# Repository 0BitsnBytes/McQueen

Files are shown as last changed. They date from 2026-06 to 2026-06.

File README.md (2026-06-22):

<h1 align="center">
  <br>
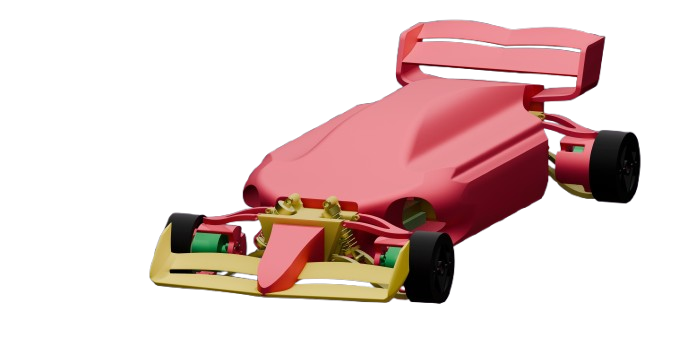
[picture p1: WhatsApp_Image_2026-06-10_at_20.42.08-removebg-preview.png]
McQueen
  
  <br>
  McQueen
  <br>
</h1>

<h4 align="center">
AWD RC Car • Custom ESC
</h4>

<p align="center">
  <a href="#specifications">Specifications</a> •
  <a href="#links">Links</a> •
  <a href="#custom-esc">Custom ESC</a> •
  <a href="#chassis">Chassis</a> •
  <a href="#build-guide">Build Guide</a> •
  <a href="#zine">Zine</a> •
  <a href="#credits">Credits</a>
</p>

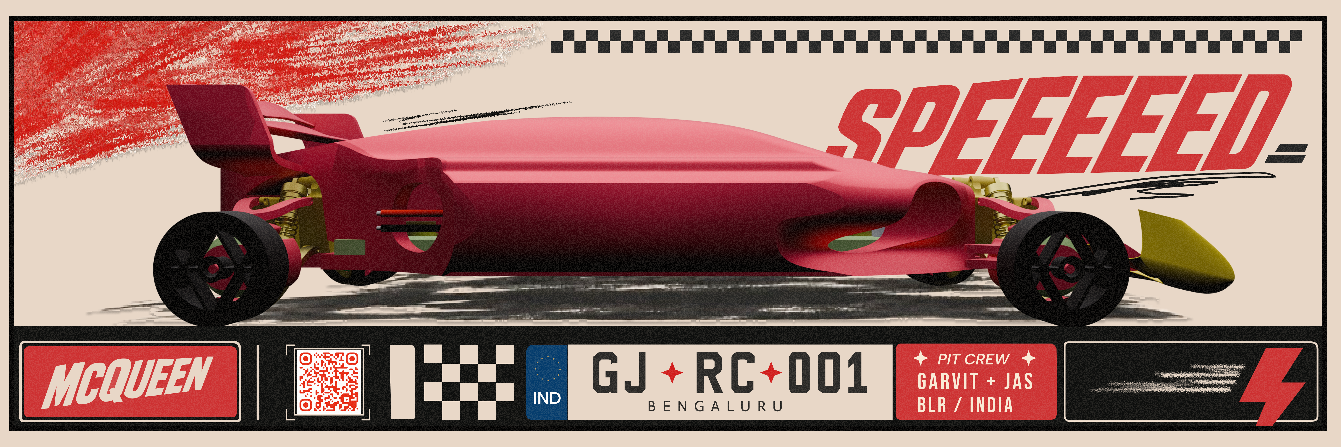
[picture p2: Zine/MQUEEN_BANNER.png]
McQueen Banner


<p>&nbsp;</p>

McQueen is an AWD RC car with 4 drone-hub-motors. Featuring a DIY 80A ESC with current sense and braking. A fully custom double wishbone suspension with an aerodynamic chassis all powered by 2 6S Lipo batteries. 

Most RC cars are seen as toys, McQueen is definitely not one of those. It is an attempt to combine high current electronics, aerodynamic bodies, and complex suspension geometries into a small RC Car. 

---

<h2 id="specifications">Specifications</h2>

<table>
<tr>
<td><b>Drive System</b></td>
<td>All Wheel Drive (AWD)</td>
</tr>

<tr>
<td><b>Motors</b></td>
<td>4× Drone Hub Motors</td>
</tr>

<tr>
<td><b>Battery</b></td>
<td>2× 6S LiPo Batteries</td>
</tr>

<tr>
<td><b>Motor Controller</b></td>
<td>Custom STM32 ESC</td>
</tr>

<tr>
<td><b>Suspension</b></td>
<td>Double Wishbone</td>
</tr>

<tr>
<td><b>Steering</b></td>
<td>Ackermann Geometry</td>
</tr>

<tr>
<td><b>Braking</b></td>
<td>Electronic Dynamic Braking</td>
</tr>

<tr>
<td><b>Chassis</b></td>
<td>Fully Custom 3D Printed Design</td>
</tr>
</table>

---

<h2 id="links">Links</h2>

If clicking the link gives 403 Forbidden, copy paste the link into your browser directly

| Resource | Link |
|---|---|
| CAD Assembly | [Onshape document](https://cad.onshape.com/documents/fc565ca3851146bee43ab660/w/08fa01b8b529e8822f765509/e/27cf93230e8926e0ab4158b0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)|
| PCB Files | [Kicanvas Viewer](https://kicanvas.org/?repo=https%3A%2F%2Fgithub.com%2F0BitsnBytes%2Fmcqueen-pcb-file-for-kicanvas) |
| Bill of Materials for ESC| [BOM for ESC](https://github.com/0BitsnBytes/McQueen/blob/main/BOM/MCQUEEEN%20-%20ESC%20BOM.csv) |
| Bill of Materials | [BOM for Car](https://github.com/0BitsnBytes/McQueen/blob/main/BOM/MCQUEEEN%20-%20ALL%20compnents.csv) |

---

<h2 id="custom-esc">Custom ESC</h2>

The ESC combines current sensing, protection circuitry, braking, and motor feedback into a compact high-current first PCB :).

<h3>Features</h3>

<ul>
<li>STM32F411CEU6 Microcontroller</li>
<li>IR21084 MOSFET Driver</li>
<li>AS5600 Position Sensor Interface</li>
<li>INA180 Current Sense Amplifier</li>
<li>MOSFET Temperature Monitoring</li>
<li>SMCJ54CA TVS Protection</li>
<li>RGB Status LED</li>
<li>Electronic Braking</li>
</ul>

<h3>Schematic</h3>

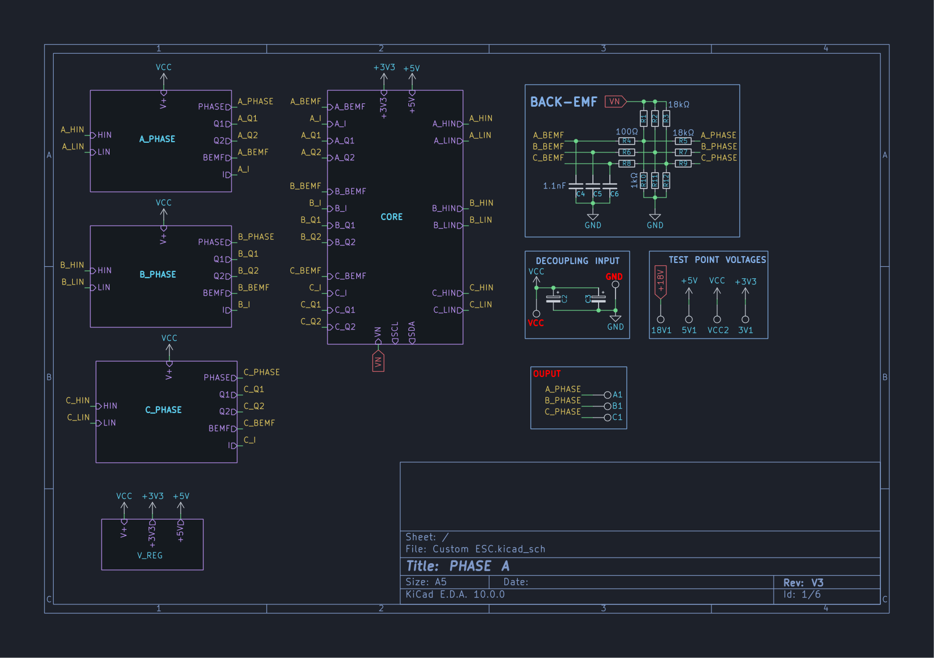
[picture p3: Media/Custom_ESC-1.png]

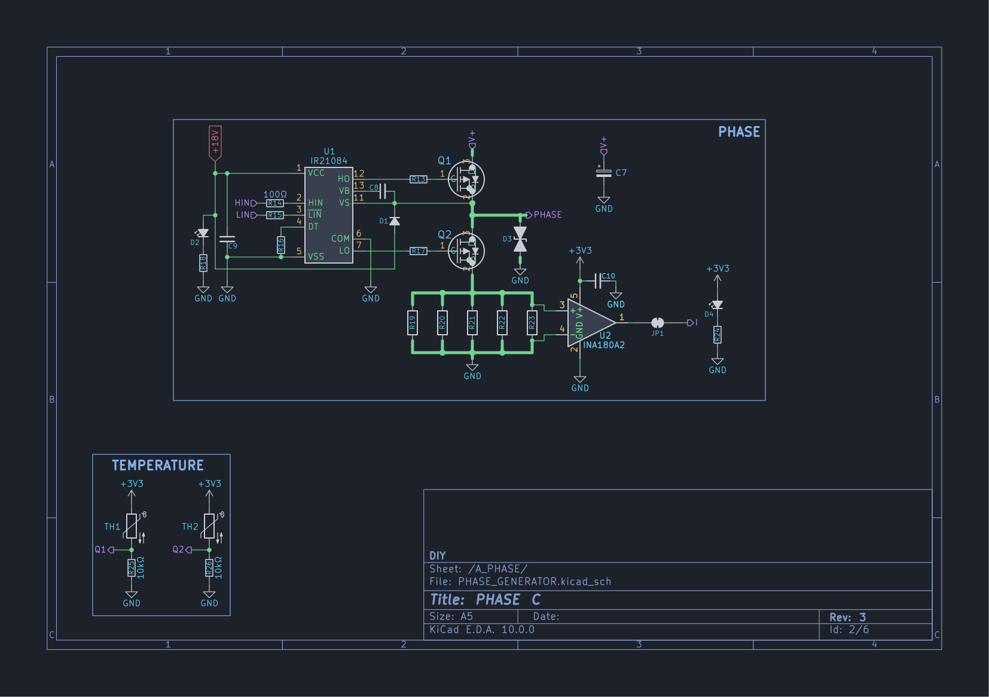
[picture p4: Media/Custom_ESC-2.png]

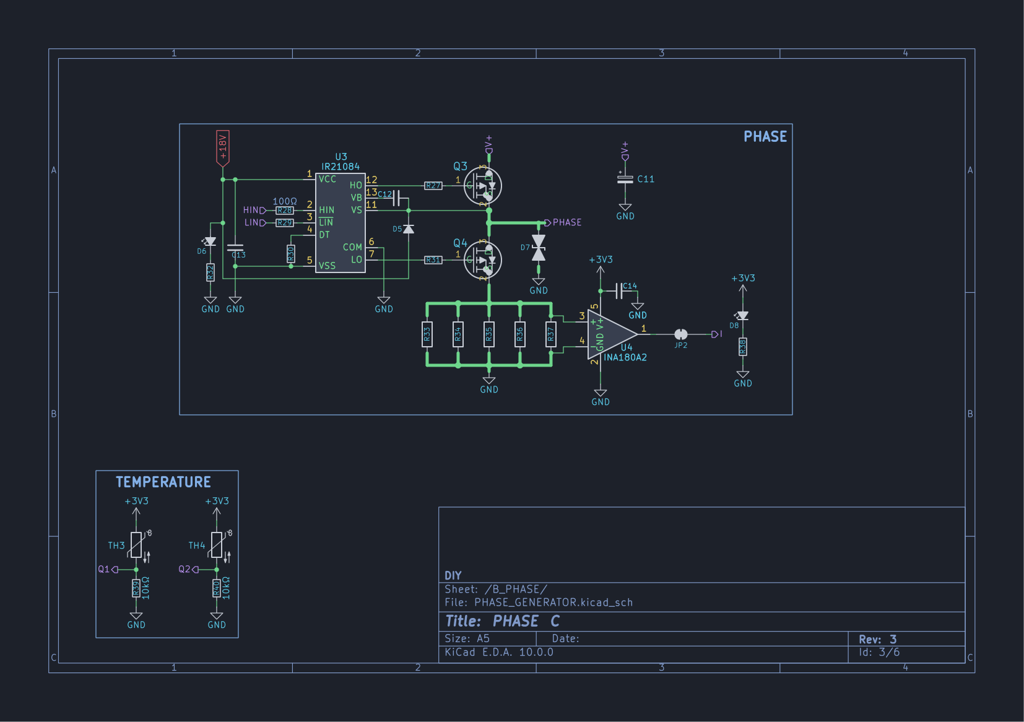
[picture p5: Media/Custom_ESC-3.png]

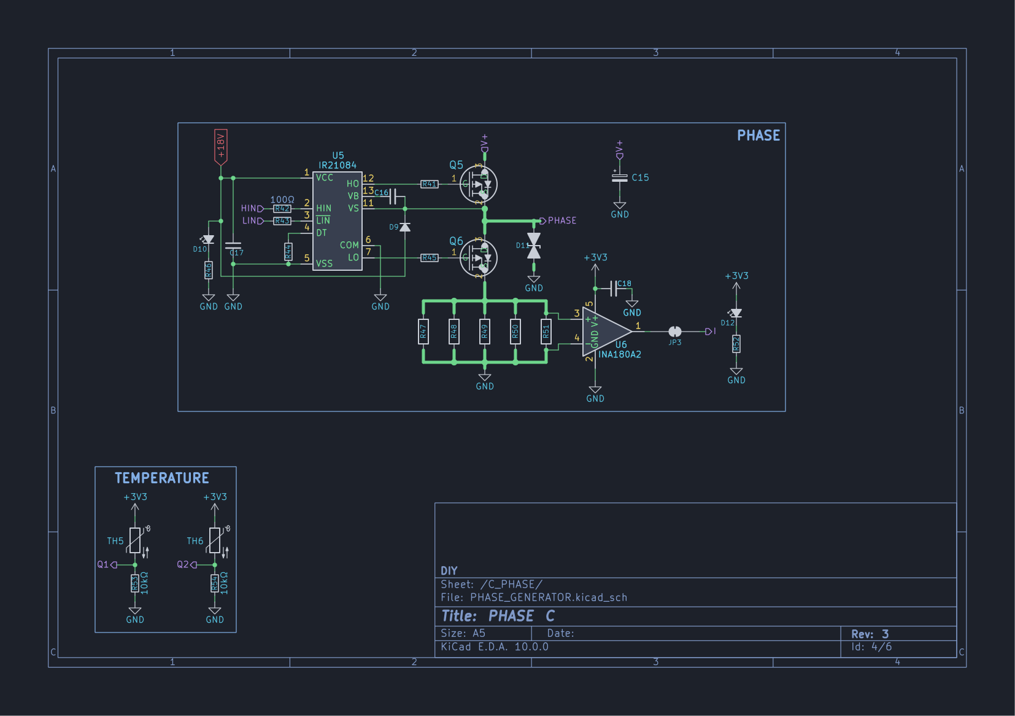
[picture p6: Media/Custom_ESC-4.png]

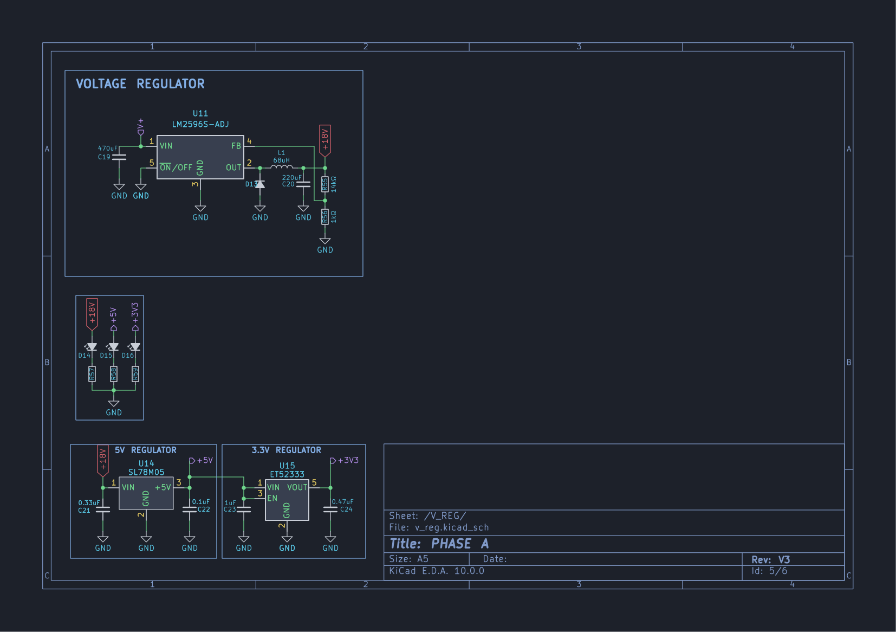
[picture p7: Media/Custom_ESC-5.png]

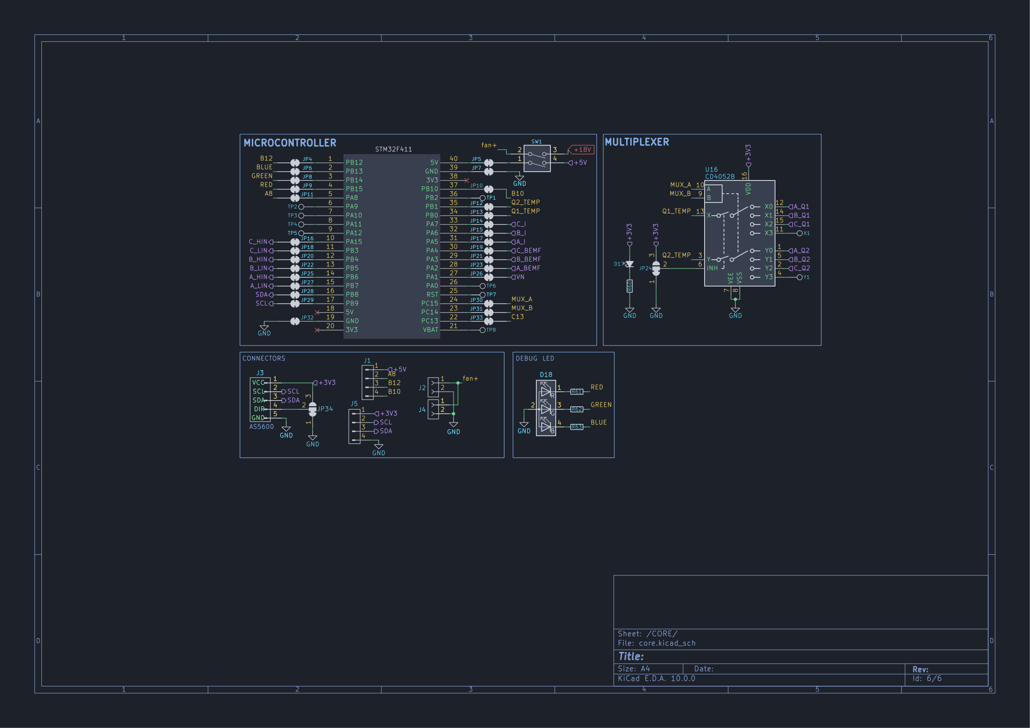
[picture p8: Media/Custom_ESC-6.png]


<h3>PCB Layers</h3>

<h4>Layer 1</h4>

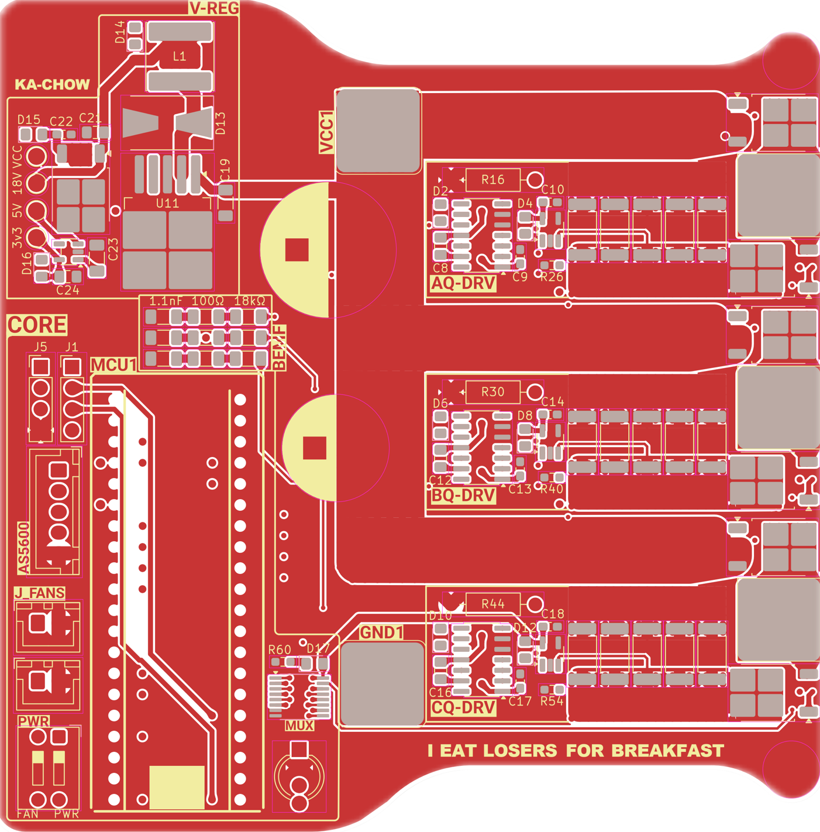
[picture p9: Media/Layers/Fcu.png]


<h4>Layer 2</h4>

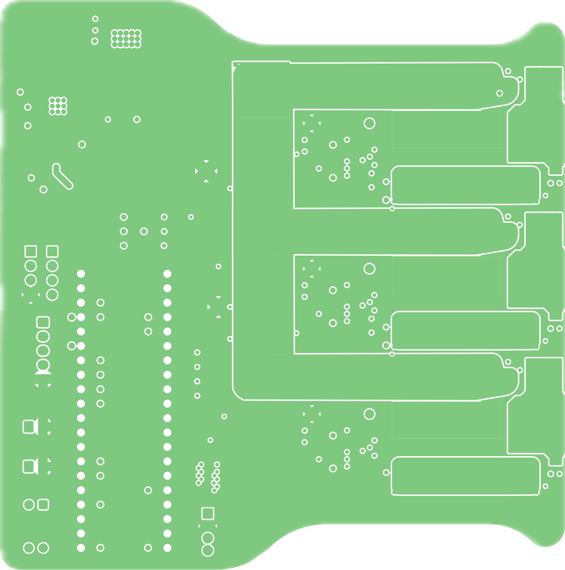
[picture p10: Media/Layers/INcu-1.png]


<h4>Layer 3</h4>

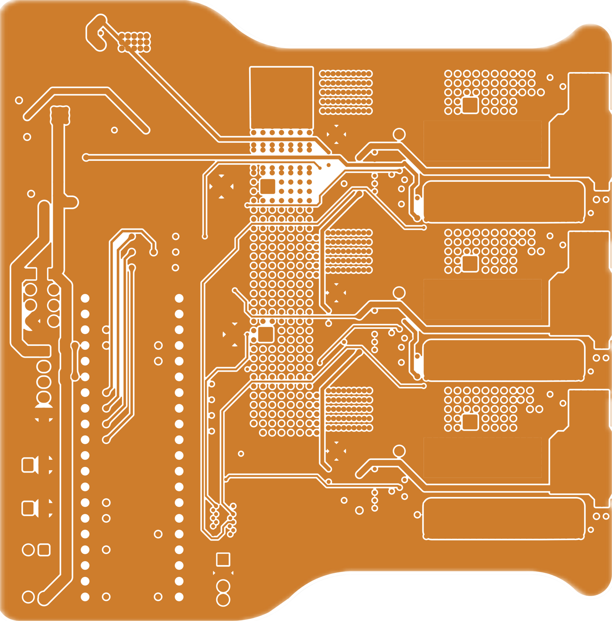
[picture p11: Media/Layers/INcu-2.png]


<h4>Layer 4</h4>

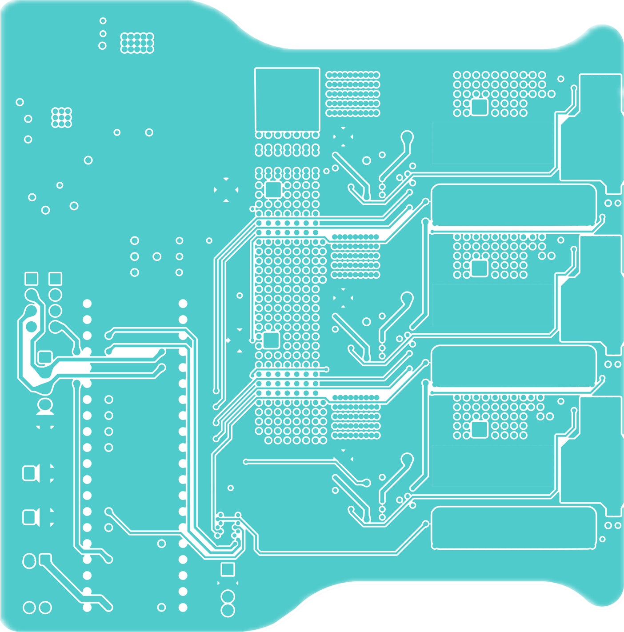
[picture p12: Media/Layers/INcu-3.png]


<h4>Layer 5</h4>

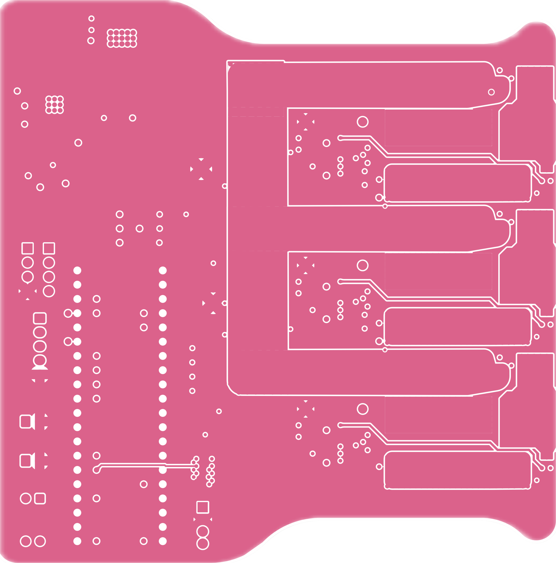
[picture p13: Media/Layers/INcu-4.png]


<h4>Layer 6</h4>

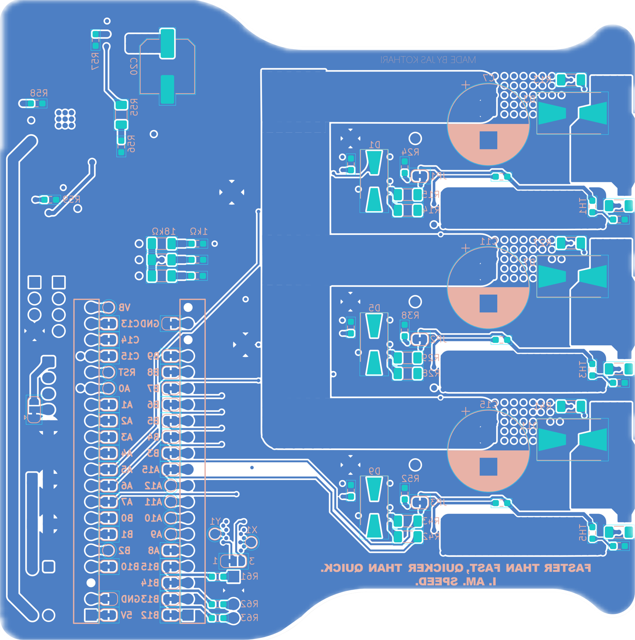
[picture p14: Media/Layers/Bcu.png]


---

<h3>Board Views</h3>

<h4>Front</h4>

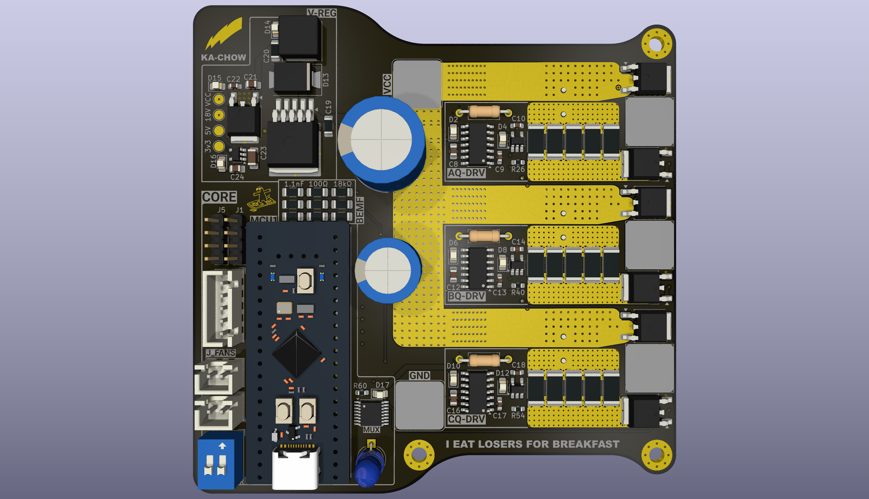
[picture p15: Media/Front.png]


<h4>Back</h4>

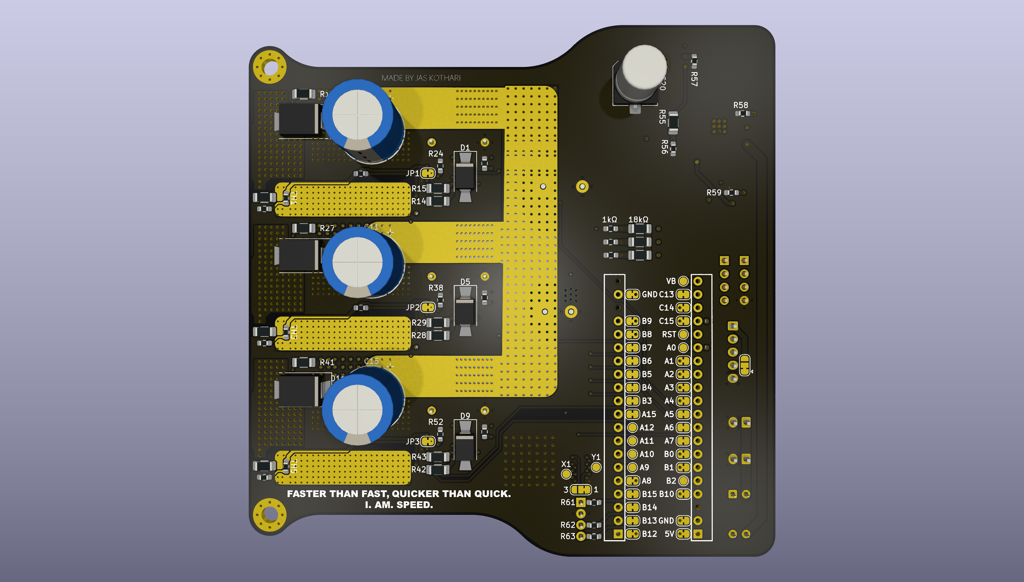
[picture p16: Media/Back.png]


---

<h2 id="chassis">Chassis</h2>

The Chassis features a fully custom double wishbone suspension system, Ackermann steering, aerodynamic chassis, and front and rear wings.

<h3>Suspension</h3>

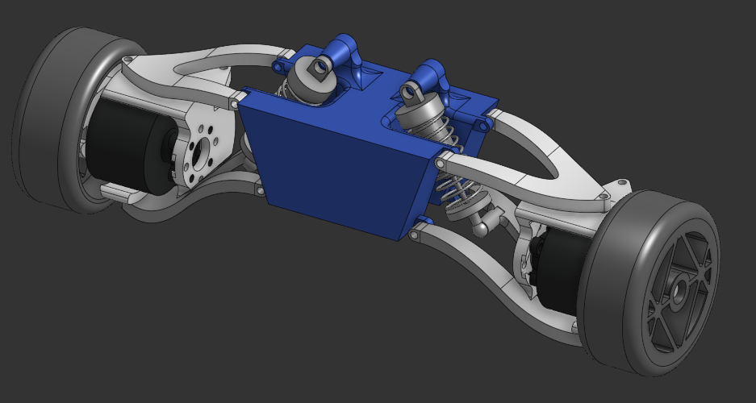
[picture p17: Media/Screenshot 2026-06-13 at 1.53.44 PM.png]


<h3>Aerodynamics</h3>


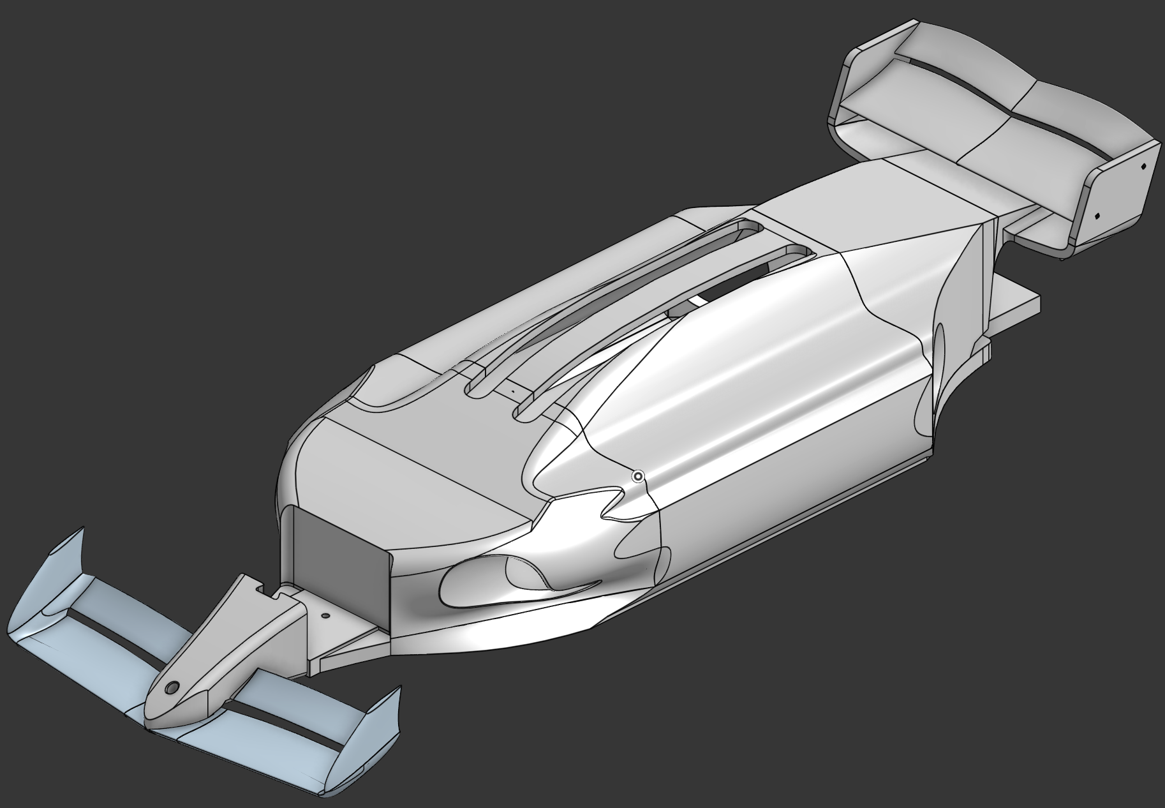
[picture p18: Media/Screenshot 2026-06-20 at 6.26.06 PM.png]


---

<h2 id="build-guide">Build Guide</h2>

McQueen consists of two major assemblies:

1. Custom ESC
2. 3D Printed Chassis

<h3>ESC</h3>

<ol>
<li>Upload the Gerber files to your preferred PCB manufacturer.</li>
<li>Select 2oz copper during fabrication.</li>
<li>Order the PCB.</li>
<li>Populate using the ESC BOM.</li>
</ol>

<h3>Chassis</h3>

<ol>
<li>Download the STL files.</li>
<li>Print all components in PETG or equivalent material.</li>
<li>Purchase hardware from the chassis BOM.</li>
<li>Follow the Onshape assembly.</li>
<li>Insert Carbon fibre square tubes in wings</li>
<li>Insert peices of filament throughout the chassis to secure it</li>
<li>Install electronics and drivetrain.</li>
<li>Secure components using M3 hardware.</li>
<li>Use cyanoacrylate adhesive where necessary.</li>
<li>Put in the magnets into the slots provided in the main chassis to make it easier to open and close the chassis.</li>
</ol>

---

<h2 id="zine">Zine</h2>

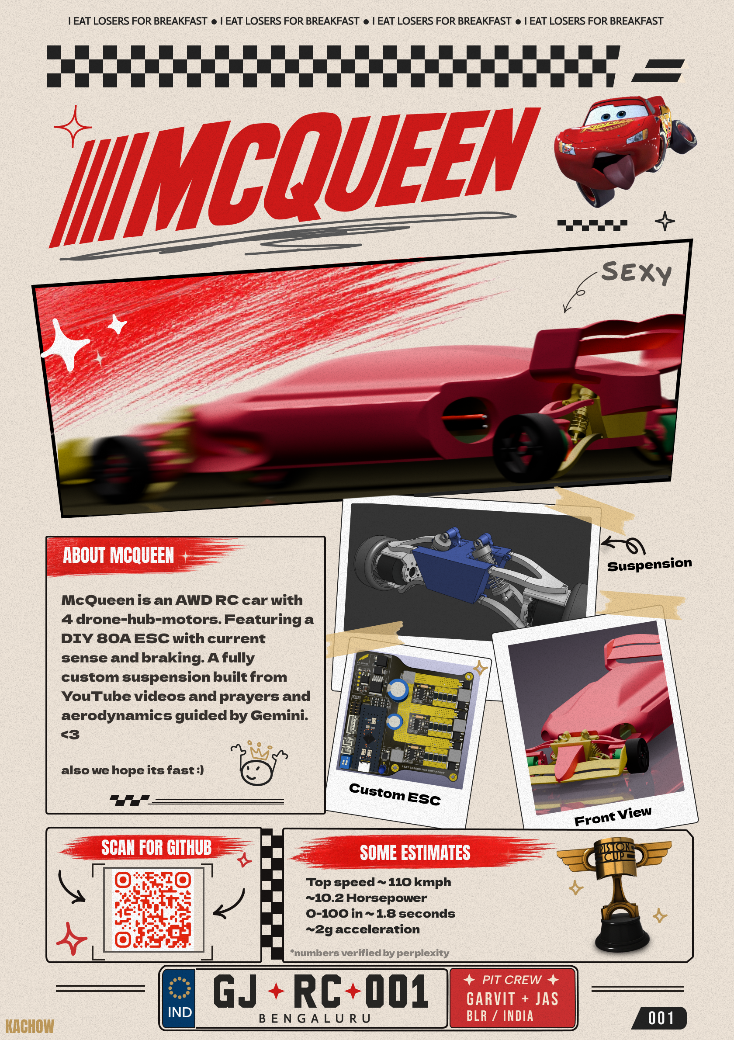
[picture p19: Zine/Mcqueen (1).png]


---

<h2 id="credits">Credits</h2>

This project uses:

<ul>
<li>KiCad for PCB Design</li>
<li>Onshape for CAD</li>
<li>Blender for Rendering</li>
<li>Figma for Documentation & Zine Design</li>
</ul>

---

<h2>License</h2>

GPL-3.0


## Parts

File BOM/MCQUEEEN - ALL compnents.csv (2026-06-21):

Component name | Quantity | Price | Total price | Link | Total Money required
FA3115 400KV BLDC | 4 | Rs2,899.00 | Rs11,596.00 | https://hitechxyz.in/products/flycci-fpv-brushless-motors-fa3115-400kv-1?_pos=1&_psq=fa3115&_ss=e&_v=1.0 | Rs64,076.08
4200mAh 6S 35C LiPo | 2 | Rs5,694.00 | Rs11,388.00 | https://robu.in/product/orange-4200mah-6s-40c80c-lithium-polymer-battery-pack-lipo?gad_source=1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 | $679.2724463624
FS-i6X RX TX | 1 | Rs6,599.00 | Rs6,599.00 | https://robu.in/product/flysky-fs-i6x-2-4ghz-10ch-afhds-2a-rc-transmitter-with-fs-ia10b-2-4ghz-10ch-receiver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 | 135.85448927248 hours
Teensy 4.1 | 1 | Rs3,399.00 | Rs3,399.00 | https://robu.in/product/teensy-4-1-development-board-with-headers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 | 679.2724463624 Koi
1/10 Scale RC wheels | 1 | Rs4,395.00 | Rs4,395.00 | https://www.amazon.in/801GTX-Brushless-Wheels-Racing-Serpent/dp/B09474HB4D
Shock Absorber | 2 | Rs532.00 | Rs1,064.00 | https://robu.in/product/wltoys-a959-aluminum-shock-absorber-1-pair
ESC PCB | 1 | Rs7,583.56 | Rs7,583.56 | https://jlcpcb.com/
ESC Components | 4 | Rs2,601.63 | Rs10,406.52 | --
Velcro Straps | 1 | Rs284.00 | Rs284.00 | https://www.amazon.in/Bonzella-Adjustable-Organizer-Multipurpose-Securing/dp/B0D41DKW5M
Servos for turning | 1 | Rs1,338.00 | Rs1,338.00 | https://robu.in/product/pro-range-ds3225-25kgcm-metal-gear-digital-servo-motor-180-degree/?gad_source=1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
Servo horn | 1 | Rs69.00 | Rs69.00 | https://robu.in/product/cnc-aluminum-steering-servo-horn-arm-futaba-standard-25t-aluminum/
Voltage checker | 1 | Rs95.00 | Rs95.00 | https://quartzcomponents.com/collections/all/products/lipo-battery-vltage-testerlow-voltage-buzzer-alarm
Ball joints | 1 | Rs1,924.00 | Rs1,924.00 | https://www.amazon.in/ShareGoo-Aluminum-Holder-TRAXXAS-Crawler/dp/B07TYXX4N3
Bearings | 1 | Rs65.00 | Rs65.00 | https://robu.in/product/radial-ball-bearing-625zz-for-3d-printer-robot-4pcs/
Solder Paste | 1 | Rs372.00 | Rs372.00 | https://www.amazon.in/MOBILE-WORLD-Solder-Paste-Rework/dp/B0DR2YWY73?mcid=31cbd004a3753bd189e576be226896a2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
Solder Flux | 1 | Rs37.00 | Rs37.00 | https://quartzcomponents.com/products/rma-223-solder-flux-paste?variant=39532236931256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
Carbon fibre | 2 | Rs54.00 | Rs108.00 | https://robu.in/product/pultruded-square-carbon-hollow-fiber-tube-22mmod-1mmid-400mml-2pcs/
3mm Rod | 1 | Rs293.00 | Rs293.00 | https://robu.in/product/pultruded-carbon-fiber-tube-hollow-3mmod-1-5mm-id-1000mm-pack-of-2/?gad_source=1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
Filament | 4 | Rs600.00 | Rs2,400.00 | https://india.numakers.com/products/petg-hs-filament?variant=43307604082857
5x3mm disc magnet | 16 | Rs10.00 | Rs160.00 | https://onlyscrews.in/products/5mm-diameter-neodymium-disc-magnets-n35?variant=51060958789945
Misc hardware (screws, nuts, etc.) | 1 | Rs500.00 | Rs500.00 | https://onlyscrews.in/

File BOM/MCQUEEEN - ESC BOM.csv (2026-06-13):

Value | Reference | Footprint | Datasheet | Qty | Link | Unit Price (₹) | Total Price (₹) | Comment
5mΩ | R19,R20,R21,R22,R23,R33,R34,R35,R36,R37,R47,R48,R49,R50,R51 | Resistor_SMD:R_2512_6332Metric_Pad1.40x3.35mm_HandSolder |  | 15 | https://robu.in/product/1-month-warranty-305/#tab-questions | 5.00 | 75
330Ω | R18,R24,R32,R38,R46,R52,R57,R58,R59,R60,R61 | Resistor_SMD:R_0603_1608Metric_Pad0.98x0.95mm_HandSolder | https://robu.in/wp-content/uploads/2024/06/C67088.pdf | 11 | https://quartzcomponents.com/collections/all/products/rc0603jr07330rl-yageo-330-ohm-0603-package-1-10w-smd-resistor-5-tolerance-pack-of-20-pieces | 5.00 | 5 | Pack has only 20 peices
LED_Small_Filled | D2,D4,D6,D8,D10,D12,D14,D15,D16,D17 | LED_SMD:LED_0805_2012Metric_Pad1.15x1.40mm_HandSolder |  | 5 | https://quartzcomponents.com/collections/all/products/red-led-smd-0805-package-pack-of-50 | 25.00 | 25 | Pack has only 50 peices
LED_SMall_Filled | D2,D4,D6,D8,D10,D12,D14,D15,D16,D18 | LED_SMD:LED_0805_2012Metric_Pad1.15x1.40mm_HandSolder |  | 5 | https://quartzcomponents.com/collections/all/products/green-led-smd-0805-package-pack-of-50 | 24.00 | 24 | Pack has only 50 peices
100Ω | R4,R6,R8,R14,R15,R28,R29,R42,R43 | Resistor_SMD:R_1206_3216Metric_Pad1.30x1.75mm_HandSolder | https://robu.in/wp-content/uploads/2024/06/C67088.pdf | 9 | https://robu.in/product/1206w4f1000t5e-uniohm-royal-ohm-250mw-thick-film-resistors-200v-%c2%b11-100%cf%89-1206-chip-resistor-surface-mount-rohs/ | 0.38 | 3.42
0.1uF | C9,C10,C13,C14,C17,C18,C22 | Capacitor_SMD:C_0603_1608Metric_Pad1.08x0.95mm_HandSolder |  | 7 | https://robu.in/product/ac0603jrx7r9bb104-yageo-cap-ceramic-0-1uf-50v-x7r-5-pad-smd-0603-125c-automotive-aec-q200-t-r/ | 1.69 | 11.83
NCU18XH103F6SRB | TH1,TH2,TH3,TH4,TH5,TH6 | Resistor_SMD:R_0603_1608Metric_Pad0.98x0.95mm_HandSolder | https://robu.in/wp-content/uploads/2025/08/C162670.pdf | 6 | https://www.digikey.in/en/products/detail/murata-electronics/NCU18XH103F60RB/7363023 | 11.76 | 70.56
10kΩ | R25,R26,R39,R40,R53,R54 | Resistor_SMD:R_0603_1608Metric_Pad0.98x0.95mm_HandSolder |  | 6 | https://robu.in/product/rc0603jr-0710kl-yageo-res-10k-5-0-25w-0603-thick-film-pack-of-10/ | 0.36 | 2.16
10Ω | R13,R17,R27,R31,R41,R45 | Resistor_SMD:R_1206_3216Metric_Pad1.30x1.75mm_HandSolder | https://robu.in/wp-content/uploads/2024/12/royal-ohm-smd-res-datasheet.pdf | 6 | https://robu.in/product/mcwr12x10r0ftlmulticomp-prosmd-chip-resistor-10-ohm-%c2%b1-1-250-mw-1206-3216-metric-thick-film-general-purpose-pack-of-10/ | 0.32 | 1.92
18kΩ | R1,R2,R3,R5,R7,R9 | Resistor_SMD:R_1206_3216Metric_Pad1.30x1.75mm_HandSolder | https://robu.in/wp-content/uploads/2024/06/C17921.pdf | 6 | https://robu.in/product/1206w4f1802t5e-uniohm-royal-ohm-250mw-thick-film-resistors-200v-%c2%b1100ppm-%e2%84%83%c2%b11-18k%cf%89-1206-chip-resistor-surface-mou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 | 0.17 | 1.02
DMT10H009LK3-13 | Q1,Q2,Q3,Q4,Q5,Q6 | Package_TO_SOT_SMD:TO-252-2 | https://robu.in/wp-content/uploads/2025/08/C6540284.pdf | 6 | https://robu.in/product/dmt10h009lk3-13-diodes-incorporated-100v-90a-3w-9m%cf%8910v-2-5v-1-n-channel-to-252dpak-mosfets-rohs/ | 58.00 | 348
1kΩ | R10,R11,R12,R56 | Resistor_SMD:R_0603_1608Metric_Pad0.98x0.95mm_HandSolder | https://robu.in/wp-content/uploads/2024/07/C138242.pdf | 4 | https://robu.in/product/rc0603fr-071kl-yageo-smd-chip-resistor-1-kohm-%c2%b1-1-100-mw-0603-1608-metric-thick-film-general-purpose-pack-of-10/ | 0.18 | 0.72
0.47uF | C8,C12,C16,C24 | Capacitor_SMD:C_0805_2012Metric_Pad1.18x1.45mm_HandSolder | https://robu.in/wp-content/uploads/2024/09/C346225.pdf | 4 | https://robu.in/product/cl21b474kbfvpne-samsung-cap-ceramic-0-47uf-50v-x7r-10-pad-smd-0805-125c-t-r-automotive-aec-q200/ | 1.20 | 4.8
INA180A2 | U2,U4,U6 | Package_TO_SOT_SMD:SOT-23-5_HandSoldering | https://www.ti.com/lit/ds/symlink/ina180.pdf?HQS=dis-dk-null-digikeymode-dsf-pf-null-wwe&ts=1775967598102 | 3 | https://www.digikey.in/en/products/detail/texas-instruments/INA180A2IDBVR/8132987 | 31.76 | 95.28
IR21084 | U1,U3,U5 | Package_SO:SOIC-14_3.9x8.7mm_P1.27mm | https://www.infineon.com/dgdl/ir2108.pdf?fileId=5546d462533600a4015355c7dc321676 | 3 | https://robu.in/product/ir21084strpbf-infenion-mosfet-igbt-driver-half-bridge-625-v-offset-10-v-to-20-v-gate-cmos-lsttl-soic-14/ | 176.00 | 528
THT | R16,R30,R44 | Resistor_THT:R_Axial_DIN0207_L6.3mm_D2.5mm_P10.16mm_Horizontal |  | 3 | https://robu.in/product/470-ohm-0-5w-metal-film-resistor-pack-of-50/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 | 1.37 | 4.11
D_TVS_Filled | D3,D7,D11 | Diode_SMD:D_SMB-SMC_Universal_Handsoldering | https://www.littelfuse.com/assetdocs/littelfuse_tvs_diode_smcj_datasheet.pdf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 | 3 | https://www.digikey.in/en/products/detail/littelfuse-inc/SMCJ54CA/762415 | 91.67 | 275.01
ES1C | D1,D5,D9 | Diode_SMD:D_SMA-SMB_Universal_Handsoldering | https://www.onsemi.com/pdf/datasheet/es1d-d.pdf | 3 | https://www.digikey.in/en/products/detail/onsemi/ES1C/976965 | 48.20 | 144.6
C_Polarized_Small | C7,C11,C15 | Capacitor_THT:CP_Radial_D12.5mm_P5.00mm |  | 3 | https://robu.in/product/100zlh220mefc12-5x25-rubycon-220uf-100v-60m%CF%89-%C2%B120-810ma120hz-plugind12-5xl25mm-aluminum-electrolytic-capacitors-leaded-rohs/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 | 29.00 | 87
1.1nF | C4,C5,C6 | Resistor_SMD:R_1206_3216Metric_Pad1.30x1.75mm_HandSolder |  | 3 | https://robu.in/product/tcc1206x7r112k500dt-cctc-smt-ceramic-capacitors-1206-x7r-112k1-1nf%c2%b110-rated-voltage50v-thickness0-85mm-tape/ | 0.97 | 2.91
Conn_01x02_Socket | J2,J4 | Connector_JST:JST_XH_B2B-XH-A_1x02_P2.50mm_Vertical |  | 2 | https://quartzcomponents.com/collections/all/products/2-pin-jst-male-2-54-pitch | 3.00 | 6
Conn_01x04_Pin | J1,J5 | Connector_PinHeader_2.54mm:PinHeader_1x04_P2.54mm_Vertical |  | 2 | https://robu.in/product/1x40-berg-strip-male-connector/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 | 9.00 | 18
CD4052B | U16 | Package_SO:TSSOP-16_4.4x5mm_P0.65mm | http://www.ti.com/lit/ds/symlink/cd4052b.pdf | 1 | https://www.digikey.in/en/products/detail/texas-instruments/CD4052BPWR/528370 | 57.65 | 57.65
ET52333 | U15 | Package_TO_SOT_SMD:SOT-23-5 | https://www.diodes.com/assets/Datasheets/AP2127.pdf | 1 | https://www.digikey.in/en/products/detail/etek-microelectronics/ET52333/28737277 | 2.84 | 2.84
SL78M05 | U14 | Package_TO_SOT_SMD:TO-252-2 | https://mm.digikey.com/Volume0/opasdata/d220001/medias/docus/7181/SL78M05%20TO-252-3.pdf | 1 | https://www.digikey.in/en/products/detail/shenzhen-slkormicro-semicon-co-ltd/SL78M05/27519042 | 16.07 | 16.07
LM2596S-ADJ | U11 | Package_TO_SOT_SMD:TO-263-5_TabPin3 | http://www.ti.com/lit/ds/symlink/lm2596.pdf | 1 | https://quartzcomponents.com/collections/all/products/lm2596adj-step-down-regulator-adjustable-output-to-263-5-package | 25.00 | 25
SW_DIP_x02 | SW1 | Button_Switch_THT:SW_DIP_SPSTx02_Slide_9.78x7.26mm_W7.62mm_P2.54mm | https://configured-product-images.s3.amazonaws.com/Datasheets/KAS.pdf | 1 | https://quartzcomponents.com/products/dip-switch-2-positions?_pos=1&_sid=b6daf7699&_ss=r | 10.00 | 10
47Ω | R63 | Resistor_SMD:R_0603_1608Metric_Pad0.98x0.95mm_HandSolder | https://robu.in/wp-content/uploads/2024/06/C67088.pdf | 1 | https://robu.in/product/47-ohm-1-4w-0603-surface-mount-chip-resistor-pack-of-100/?gad_source=1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 | 0.46 | 0.46
470Ω | R62 | Resistor_SMD:R_0603_1608Metric_Pad0.98x0.95mm_HandSolder | https://robu.in/wp-content/uploads/2024/06/C67088.pdf | 1 | https://robu.in/product/470-ohm-1-4w-0603-surface-mount-chip-resistor-pack-of-100/?gad_source=1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 | 0.45 | 0.45
14kΩ | R55 | Resistor_SMD:R_1206_3216Metric_Pad1.30x1.75mm_HandSolder | https://robu.in/wp-content/uploads/2024/07/C138242.pdf | 1 | https://robu.in/product/rc0603fr-0714kl-yageo-res-thick-film-0603-14k-ohm-1-0-1w1-10w-%c2%b1100ppm-c-pad-smd-t-r/ | 0.65 | 0.65
U? | MCU1 | STM32F4x1CxU6 CoreBoard WeActStudio:STM32F4x1CxU6 WeActStudio |  | 1 | https://robu.in/product/stm32f411ceu6-minimum-system-board-microcomputer-stm32-arm-core-board/ | 473.00 | 473
68uH | L1 | Inductor_SMD:L_Changjiang_FNR8040S |  | 1 | https://robu.in/product/swpa8040s680mt-68uh-20-1-25a-255ohm-smd-8-0x8-0x4-0mm-power-inductors-pack-of-2/ | 20.00 | 20 | Pack of 2
Conn_01x05_Pin | J3 | Connector_JST:JST_XH_B5B-XH-A_1x05_P2.50mm_Vertical |  | 1 | https://quartzcomponents.com/products/5-pin-jst-xh-male-connector-5-24mm-pitch | 2.00 | 2
LED_RAGB | D18 | LED_THT:LED_D5.0mm-4_RGB_Wide_Pins |  | 1 | https://quartzcomponents.com/products/rgb-led-5mm | 4.00 | 4
SS34 | D13 | Diode_SMD:D_SMB-SMC_Universal_Handsoldering |  | 1 | https://quartzcomponents.com/collections/all/products/ss34-3a-40v-schottky-diode-big-smd-do-214ab-smc | 3.00 | 3
1uF | C23 | Capacitor_SMD:C_1206_3216Metric_Pad1.33x1.80mm_HandSolder |  | 1 | https://robu.in/product/1206b105k500ct-walsin-smd-multilayer-ceramic-capacitor-1-%c2%b5f-50-v-1206-3216-metric-%c2%b1-10-x7r/ | 0.70 | 0.7
0.33uF | C21 | Capacitor_SMD:C_0805_2012Metric_Pad1.18x1.45mm_HandSolder | https://robu.in/wp-content/uploads/2024/06/C107132.pdf | 1 | https://robu.in/product/cc0805kkx7r9bb334-yageo-cap-ceramic-0-33uf-50v-x7r-10-pad-smd-0805-125c-t-r/ | 0.47 | 0.47
220uF | C20 | Resistor_SMD:R_1206_3216Metric_Pad1.30x1.75mm_HandSolder |  | 1 | https://robu.in/product/220uf-50v-surface-mount-electrolytic-capacitor-reel-of-500/ | 9.00 | 9
470uF | C19 | Resistor_SMD:R_1206_3216Metric_Pad1.30x1.75mm_HandSolder |  | 1 | https://robu.in/product/63zlh470mefc12-5x25-rubycon-470uf-63v-%C2%B120-plugind12-5xl25mm-aluminum-electrolytic-capacitors-leaded-rohs/ | 46.00 | 46
10uf | C3 | Capacitor_THT:CP_Radial_D12.5mm_P5.00mm |  | 1 | https://robu.in/product/h2100m100c080hy-hyncdz-plugind6-3xl8mm-polymer-aluminum-capacitors-rohs/ | 6.00 | 6
1000uf | C2 | Capacitor_THT:CP_Radial_D16.0mm_P7.50mm |  | 1 | https://quartzcomponents.com/collections/all/products/1000-%C2%B5f-63v-radial-electrolytic-capacitor-through-hole-package | 23.00 | 23
AS5600 | -- | -- | https://files.seeedstudio.com/wiki/Grove-12-bit-Magnetic-Rotary-Position-Sensor-AS5600/res/Magnetic%20Rotary%20Position%20Sensor%20AS5600%20Datasheet.pdf | 1 | https://robu.in/product/magnetic-encoder-sensor-module-as5600/#tab-robu_other_tab | 149.00 | 149
JST-XH cable | -- | -- | -- | 1 | https://quartzcomponents.com/products/5-pin-jst-sm-connector-with-wire-5-24mm-pitch | 13.00 | 13

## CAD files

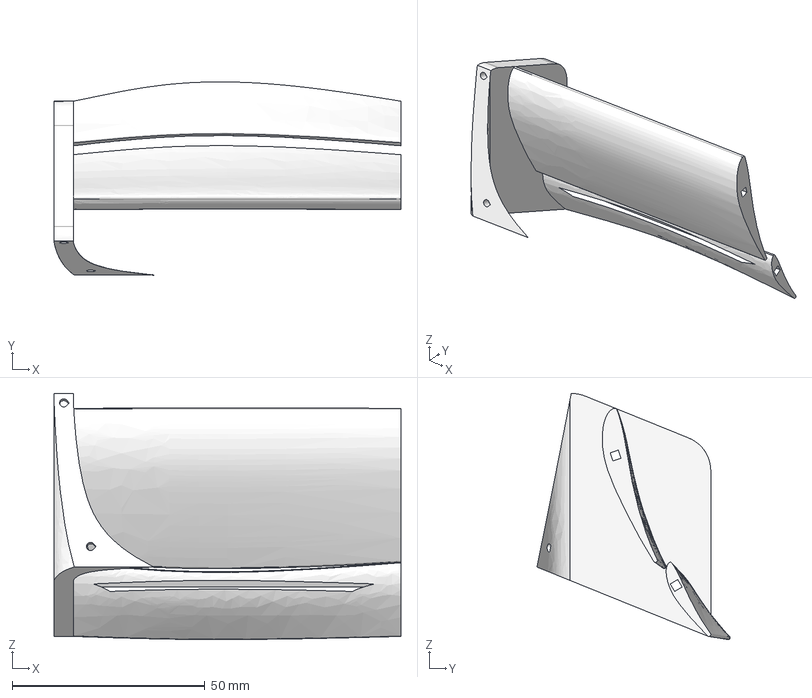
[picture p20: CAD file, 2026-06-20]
3D MODELS/Aero/Back Aero/Main chassis - Part 57.step
90.0 x 50.1 x 63.8 mm

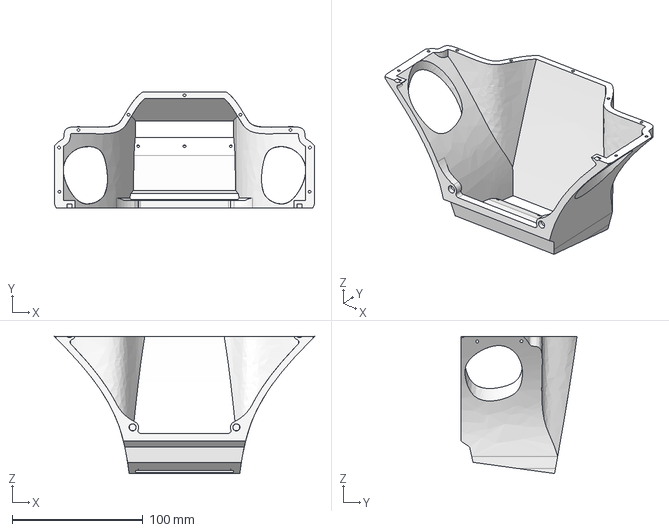
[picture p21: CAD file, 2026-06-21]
3D MODELS/Chassis/Main chassis - Part 54.step
199.1 x 88.9 x 104.9 mm

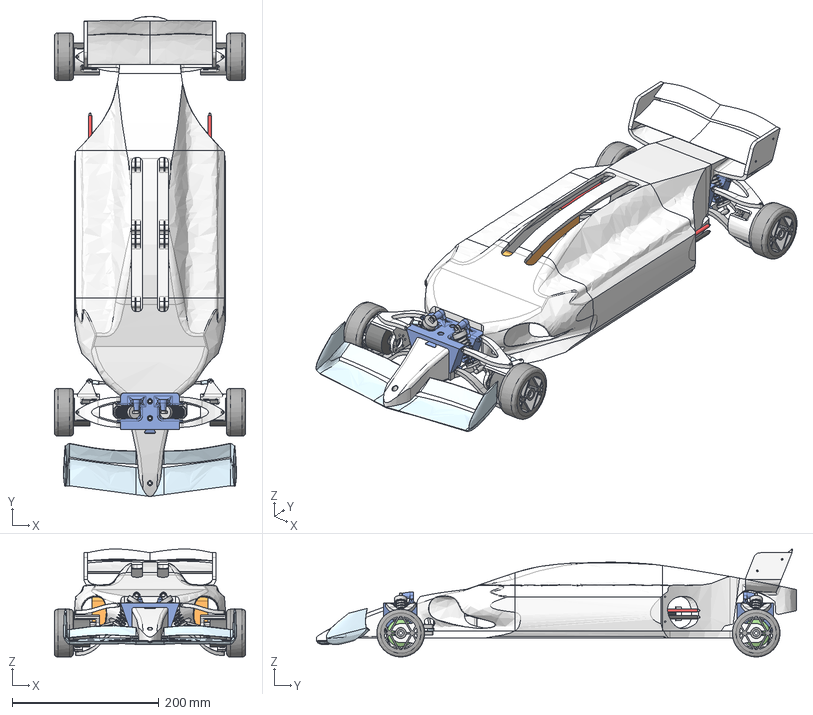
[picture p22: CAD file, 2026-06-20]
3D MODELS/FULL ASSEMBLY (DO NOT PRINT).step
260.6 x 653.6 x 146.9 mm
LiPo - x 2
Lead + x 2
Screw holder BLDC x 2
PRT0002 x 8
Balance connector x 4
Balance + x 2
SERVO ARM HORN 25T ALUMINIUM
Lead - x 2
Balance - x 12
LiPo + x 2
Main LiPo x 2
Sticker x 2
DS3235SG 35KG x 2

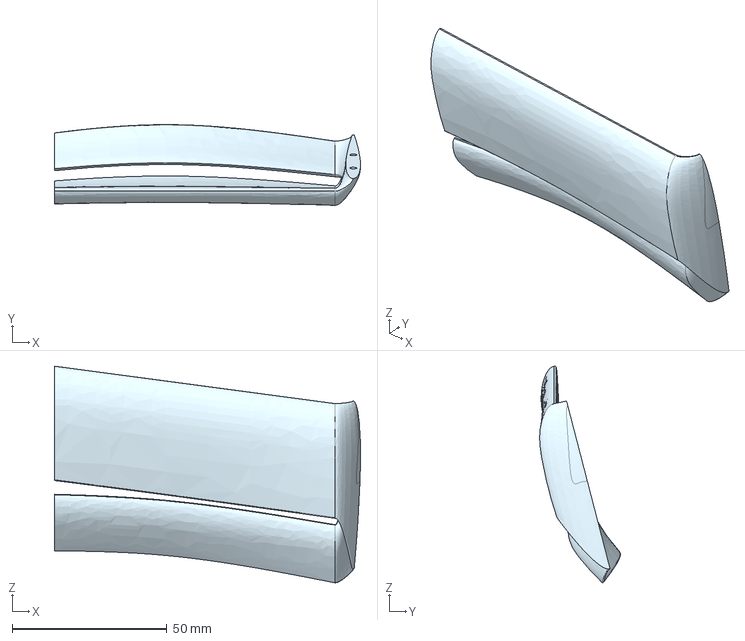
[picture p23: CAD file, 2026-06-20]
3D MODELS/Aero/Front Aero/Main chassis - Part 1.step
98.7 x 26.1 x 69.9 mm

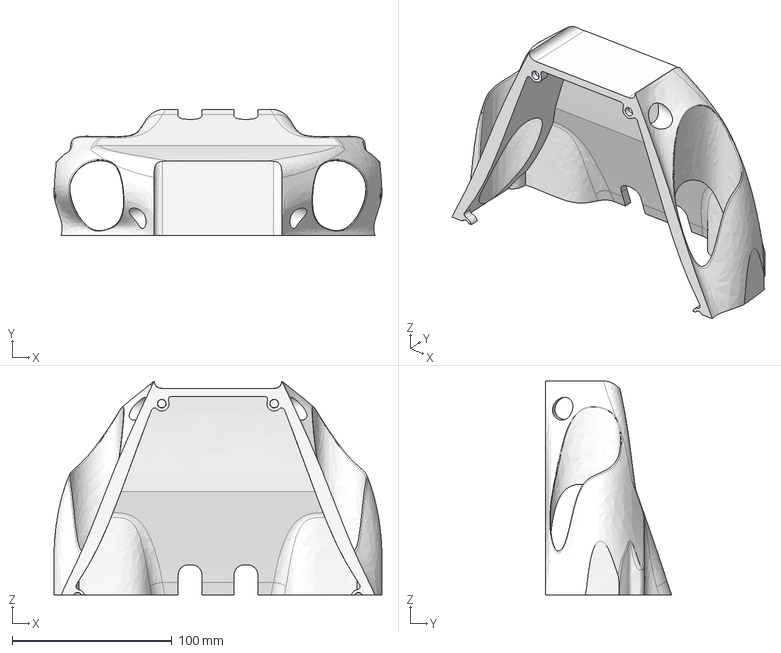
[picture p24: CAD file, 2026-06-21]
3D MODELS/Chassis/Main chassis - Part 52.step
205.5 x 79.1 x 133.9 mm

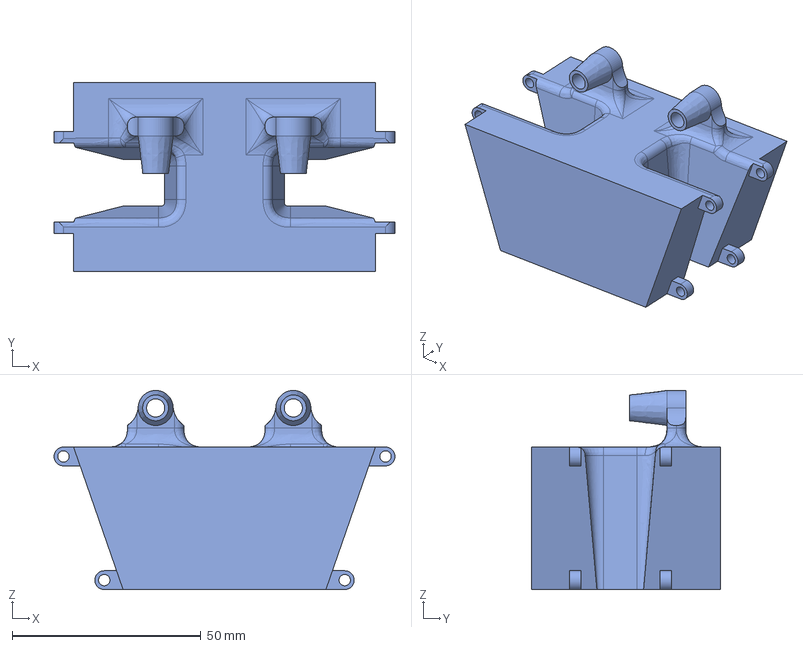
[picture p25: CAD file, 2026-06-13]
3D MODELS/Main chassis - Part 37.step
90.4 x 50.0 x 52.8 mm

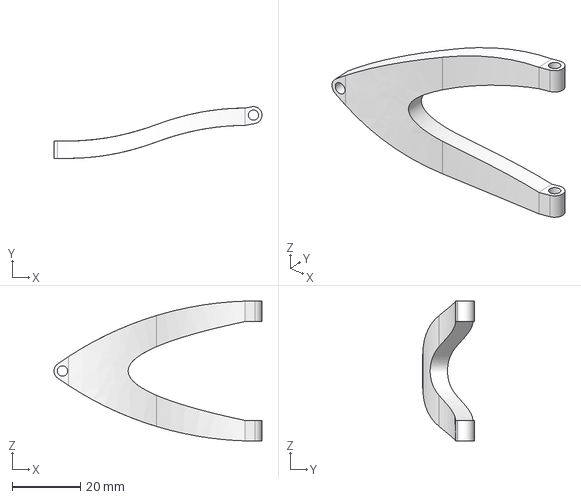
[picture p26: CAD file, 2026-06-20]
3D MODELS/Suspension/Back suspension/Main chassis - Part 44.step
61.0 x 15.2 x 41.0 mm

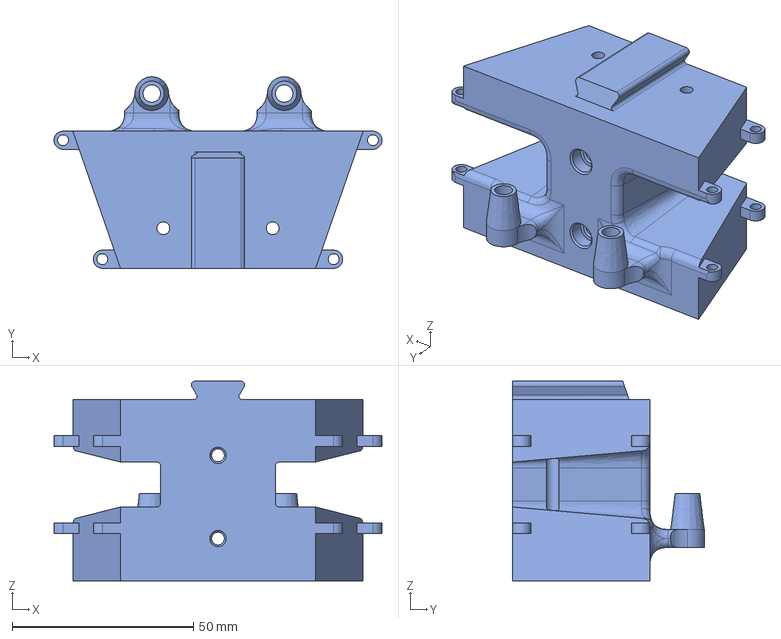
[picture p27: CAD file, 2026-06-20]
3D MODELS/Suspension/Front Suspension/Main chassis - Part 33.step
90.4 x 52.8 x 55.0 mm

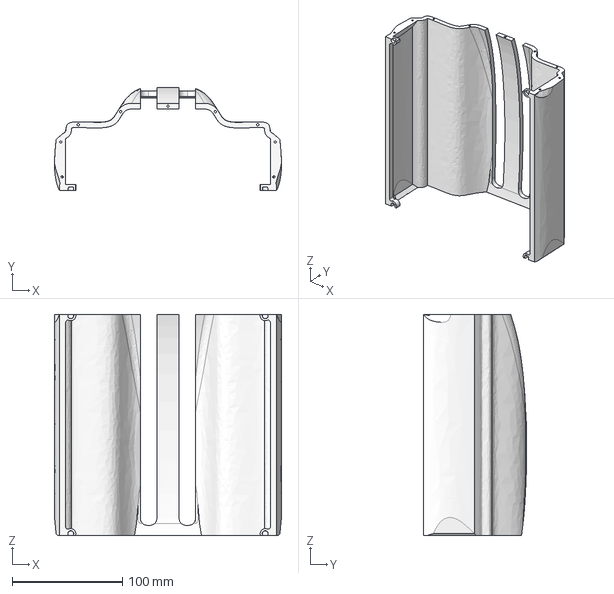
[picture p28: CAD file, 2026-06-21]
3D MODELS/Chassis/Main chassis - Part 53.step
205.5 x 93.7 x 200.5 mm

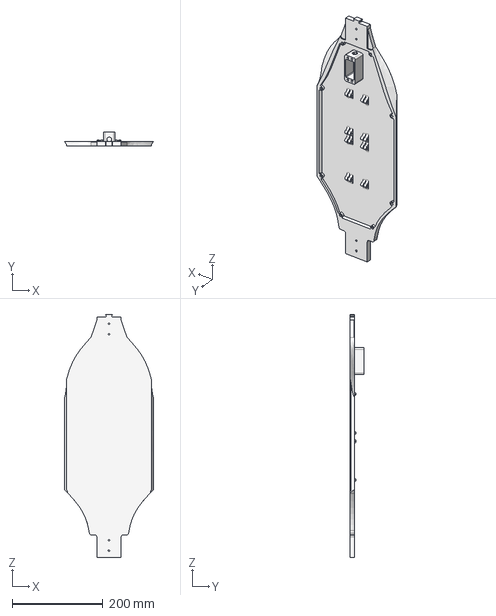
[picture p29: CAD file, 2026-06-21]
3D MODELS/Chassis/Main chassis - Part 51.step
196.5 x 30.0 x 536.1 mm

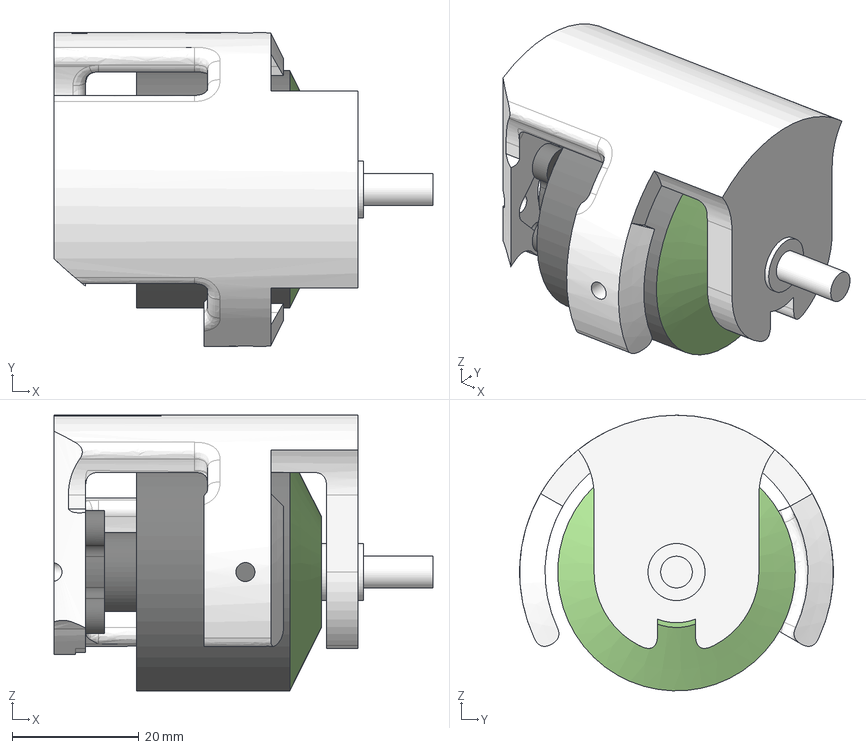
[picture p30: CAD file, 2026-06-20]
3D MODELS/Suspension/Back suspension/Main chassis - Part 6.step
59.8 x 49.5 x 43.5 mm

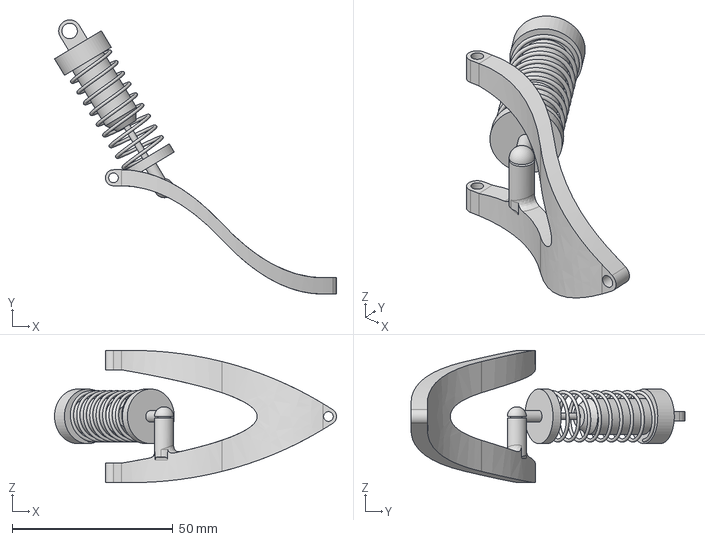
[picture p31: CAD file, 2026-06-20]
3D MODELS/Suspension/Front Suspension/Main chassis - Part 2.step
87.7 x 85.2 x 41.1 mm

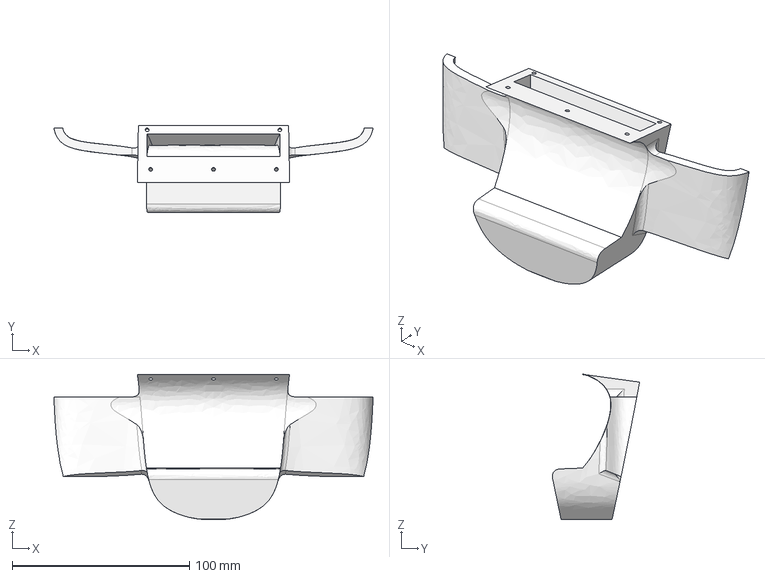
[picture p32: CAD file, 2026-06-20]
3D MODELS/Chassis/Main chassis - Part 55.step
180.0 x 49.2 x 82.0 mm

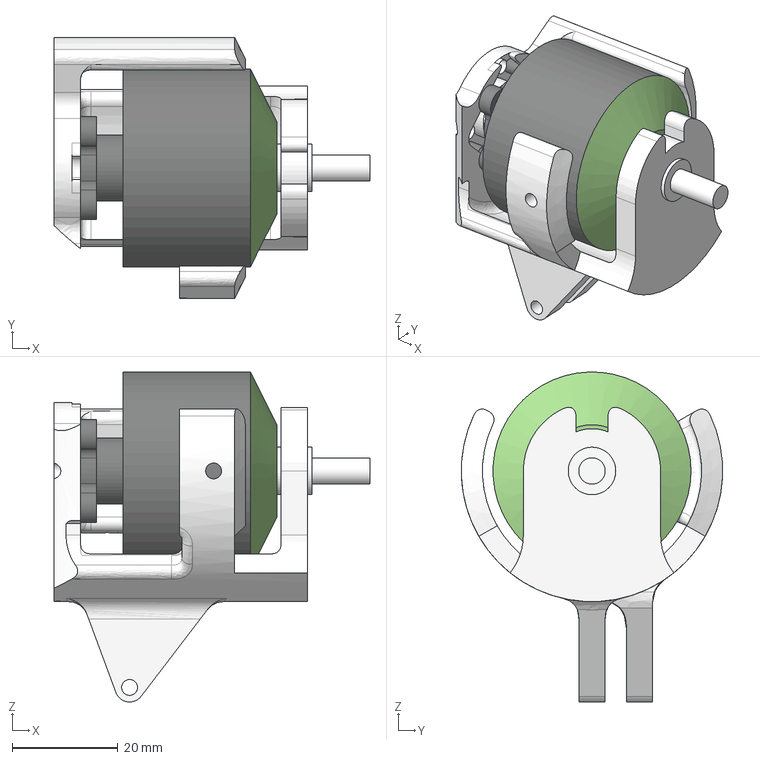
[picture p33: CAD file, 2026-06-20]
3D MODELS/Suspension/Front Suspension/Main chassis - Part 6.step
59.8 x 49.5 x 62.5 mm

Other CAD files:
3D MODELS/Aero/Back Aero/Main chassis - Part 56.step
3D MODELS/Suspension/Back suspension/Main chassis - Part 42.step
3D MODELS/Suspension/Front Suspension/Main chassis - Top Left suspension arm.step
3D MODELS/Chassis/Main chassis - Part 69.step
3D MODELS/Aero/Front Aero/Main chassis - Part 1 (1).step
3D MODELS/Aero/Front Aero/Main chassis - Part 1 (2).step
3D MODELS/Aero/Front Aero/Main chassis - Part 1 (3).step
3D MODELS/Aero/Front Aero/Main chassis - Part 1 (4).step
3D MODELS/Suspension/Back suspension/Main chassis - Part 2 (1).step
3D MODELS/Suspension/Back suspension/Main chassis - Part 2.step
3D MODELS/Suspension/Back suspension/Main chassis - Part 41.step
3D MODELS/Suspension/Back suspension/Main chassis - Screw holder BLDC.step
3D MODELS/Suspension/Front Suspension/Main chassis - Part 2 (1).step
3D MODELS/Suspension/Front Suspension/Main chassis - Part 34.step
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

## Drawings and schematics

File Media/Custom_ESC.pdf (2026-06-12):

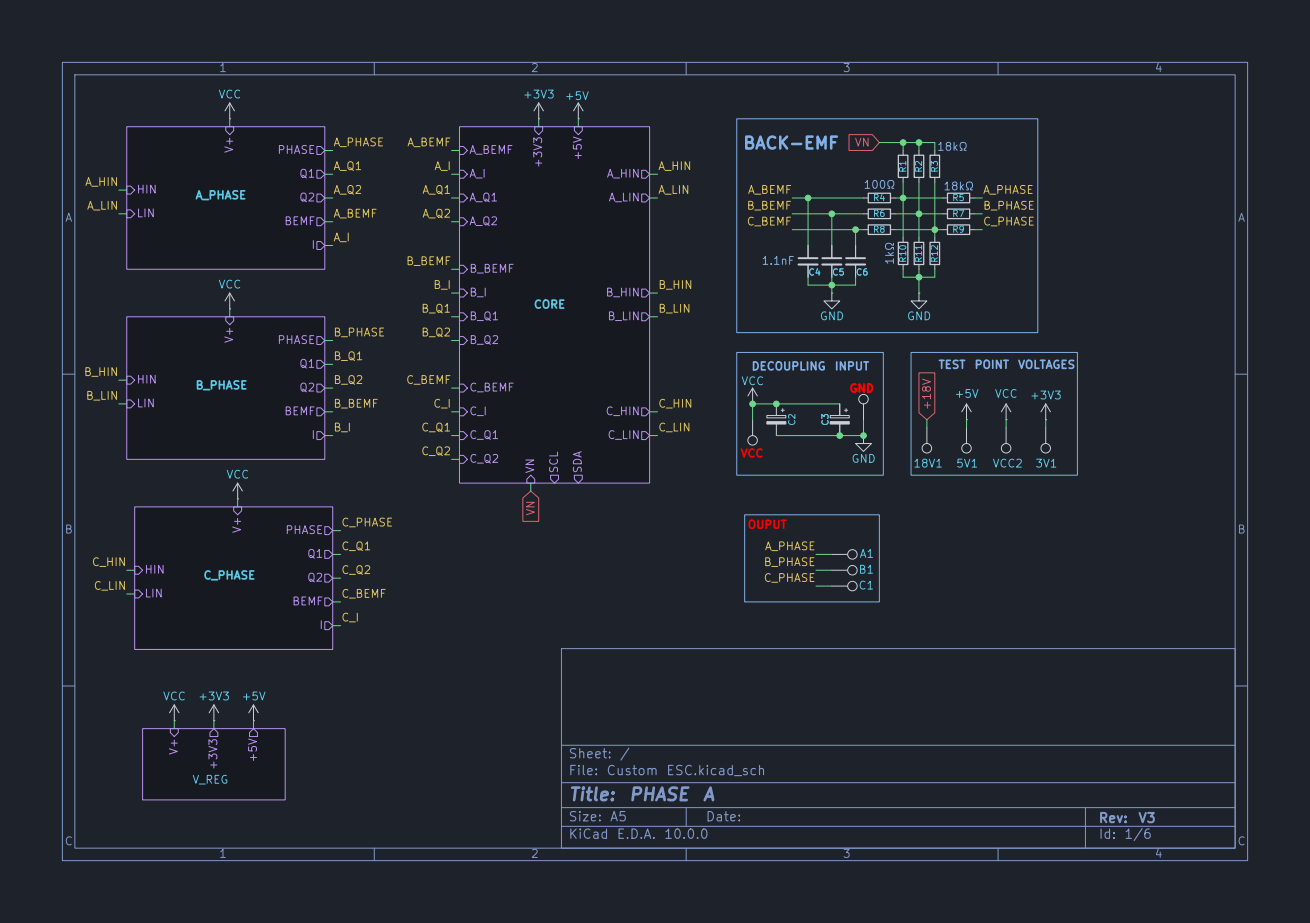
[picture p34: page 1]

Size: A5 | Rev: V3 | C Date:
KiCad E.D.A. 10.0.0 | Id: 1/6

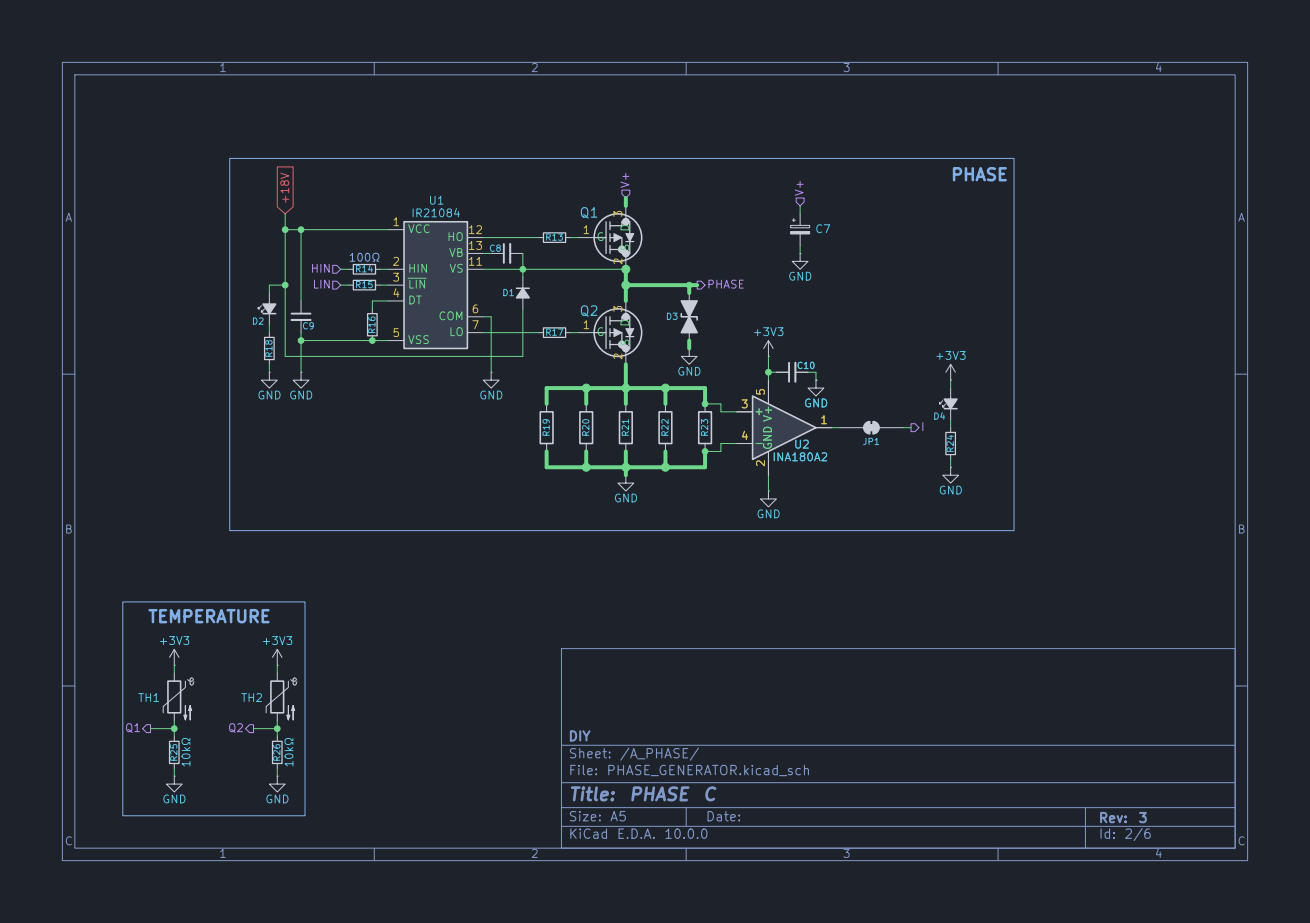
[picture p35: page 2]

Size: A5 | Rev: 3 | C Date:
KiCad E.D.A. 10.0.0 | Id: 2/6

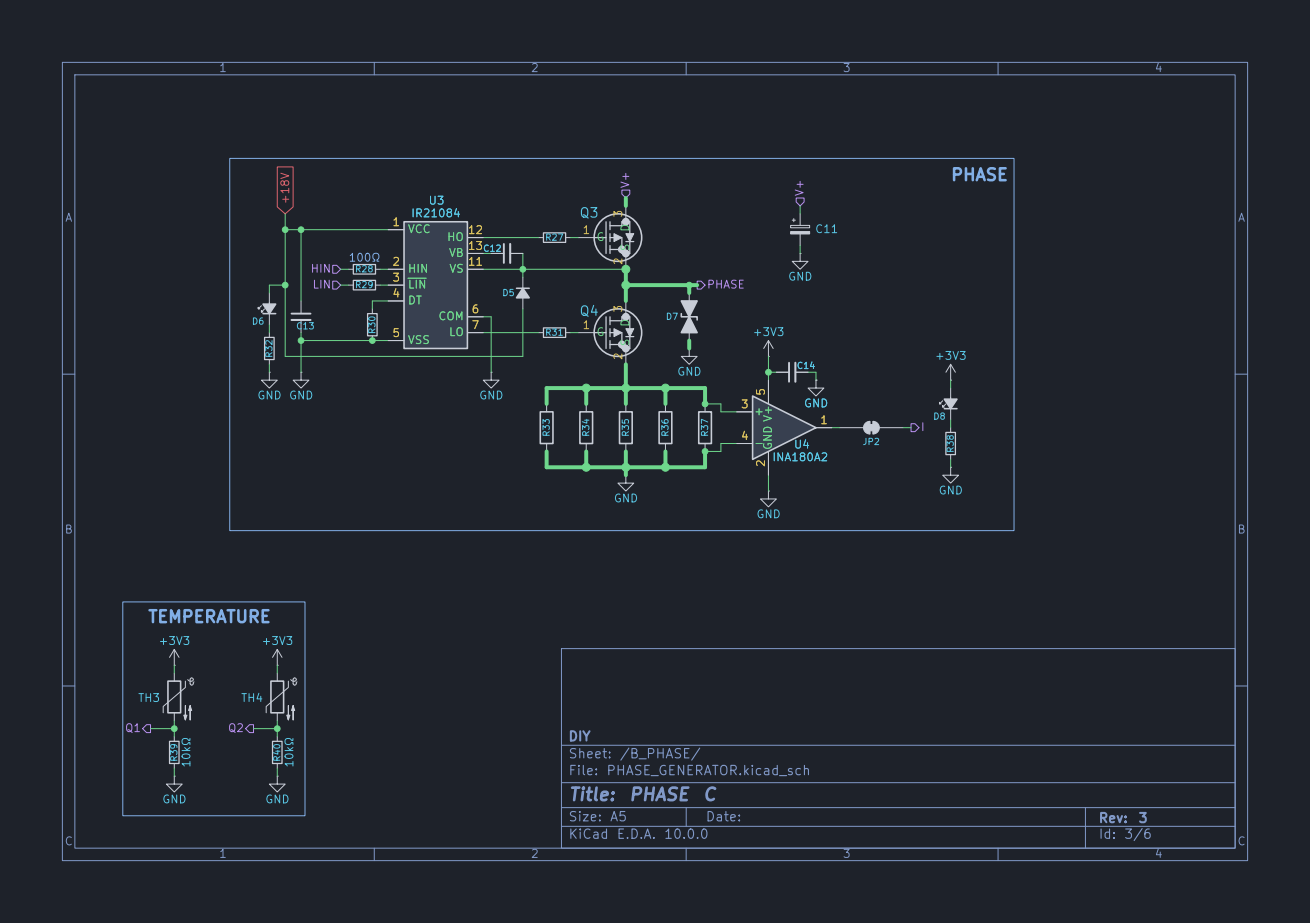
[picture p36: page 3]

Size: A5 | Rev: 3 | C Date:
KiCad E.D.A. 10.0.0 | Id: 3/6

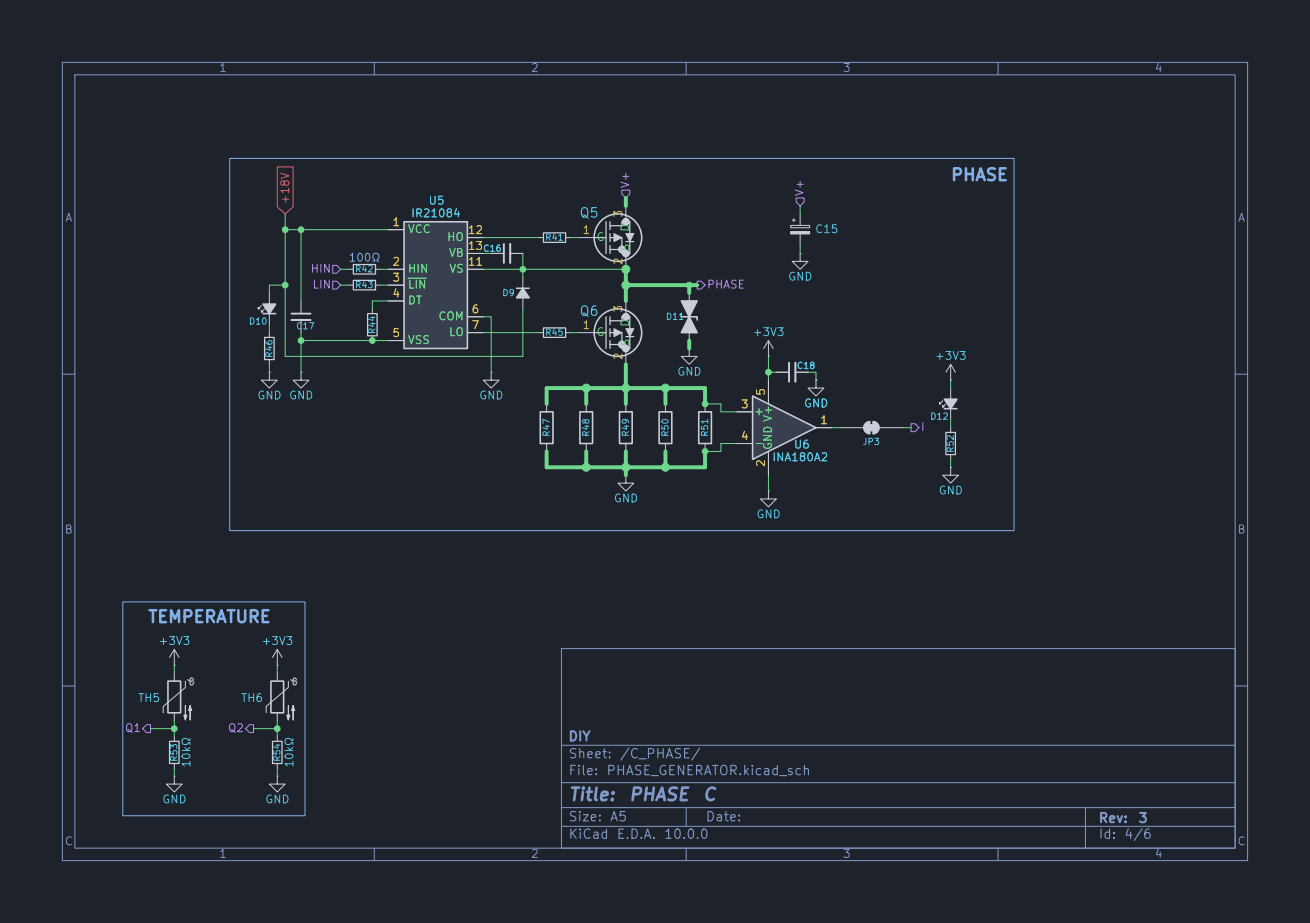
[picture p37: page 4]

Size: A5 | Rev: 3 | C Date:
KiCad E.D.A. 10.0.0 | Id: 4/6

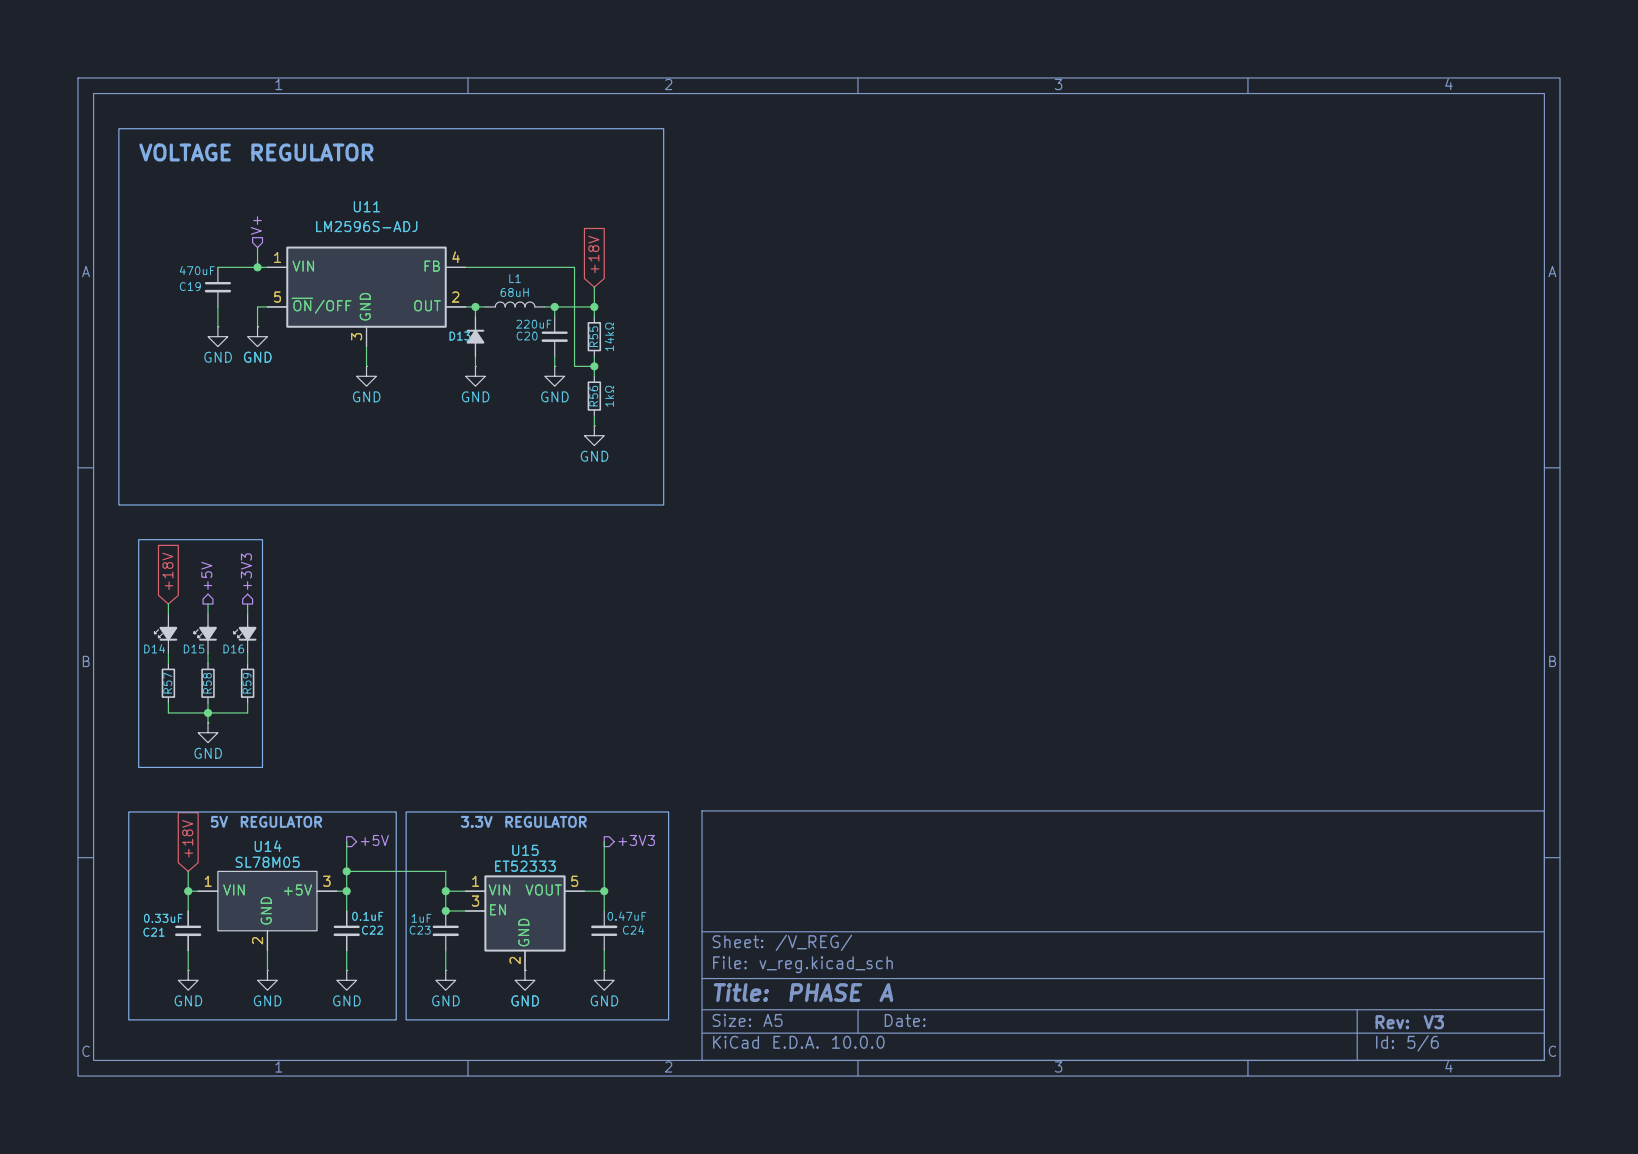
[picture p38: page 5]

Size: A5 | Rev: V3 | C Date:
KiCad E.D.A. 10.0.0 | Id: 5/6

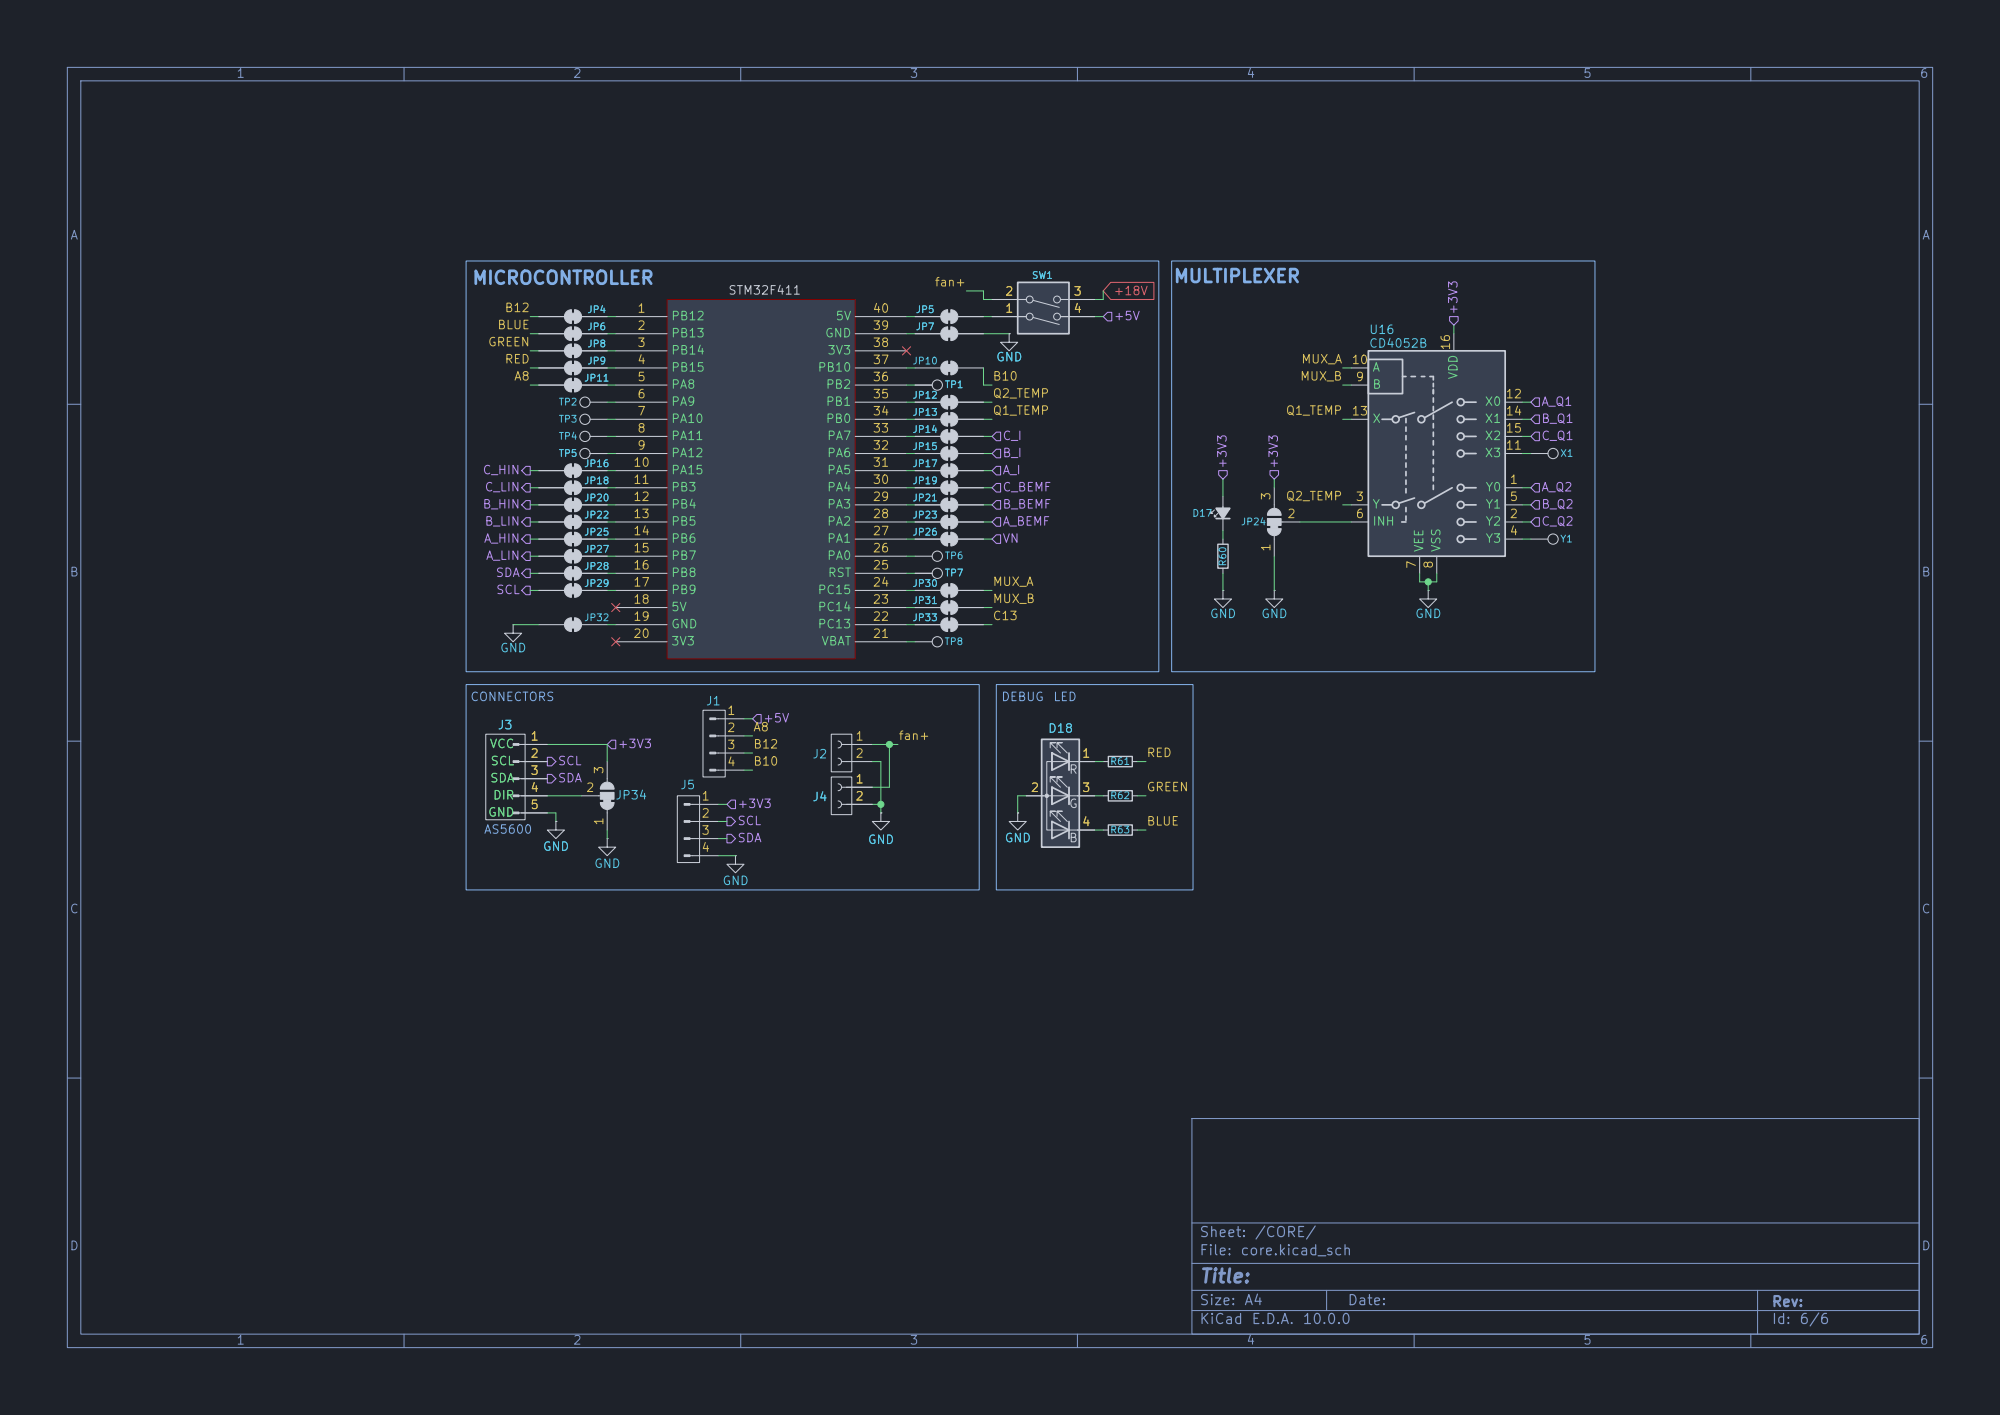
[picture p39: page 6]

Size: A4 | Rev:
KiCad E.D.A. 10.0.0 | Id: 6/6

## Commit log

2026-05-19 added all the files
    [Custom ESC.kicad_sch, PHASE_GENERATOR.kicad_sch, core.kicad_sch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]
2026-06-10 Rename Custom ESC.png to Custom ESC.png
2026-06-10 Rename Main chassis.step to 3D Models/Main chassis.step
    [Main chassis.step]
2026-06-10 Rename Main chassis.step to Full assembly.step
    [Full assembly.step]
2026-06-10 Add BLDC Mount 3D model file
    [BLDC Mount.step]
2026-06-12 Rename Custom ESC-B_Cu.gbl to Gerber/Custom ESC-B_Cu.gbl
    [Custom ESC-B_Cu.gbl]
2026-06-12 Rename Custom ESC-B_Mask.gbs to Gerber/Custom ESC-B_Mask.gbs
    [Custom ESC-B_Mask.gbs]
2026-06-12 Rename Custom ESC-B_Paste.gbp to Gerber/Custom ESC-B_Paste.gbp
    [Custom ESC-B_Paste.gbp]
2026-06-12 Moving files to gerber
    [Custom ESC-B_Silkscreen.gbo, Custom ESC-Edge_Cuts.gm1, Custom ESC-F_Cu.gtl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]
2026-06-12 Update PCB layer images in README
2026-06-12 Create Custom ESC.pdf
2026-06-12 Redid gerber
    [Custom ESC-B_Cu.gbl, Custom ESC-B_Mask.gbs, Custom ESC-B_Paste.gbp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]
2026-06-13 Rename Custom ESC.pdf to Custom_ESC.pdf
2026-06-13 gerber redo
    [Custom ESC-B_Cu.gbl, Custom ESC-B_Mask.gbs, Custom ESC-B_Paste.gbp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]
2026-06-13 Adjust image width for PCB Layer 1
    Updated image width for PCB Layer 1 in README.
2026-06-13 Create MCQUEEEN - ESC BOM.csv
    [MCQUEEEN - ESC BOM.csv]
2026-06-13 Revise BOM with new components and corrections
    Updated the BOM with new components and corrected existing entries.
    [MCQUEEEN - ESC BOM.csv]
2026-06-13 Update MCQUEEEN - ESC BOM.csv
    [MCQUEEEN - ESC BOM.csv]
2026-06-13 Rename Main chassis - Part 37.step to 3D MODELS/Main chassis - Part 37.step
    [Main chassis - Part 37.step]
2026-06-13 Rename 3D MODELS/Main chassis - Part 37.step to 3D MODELS/Suspension/Main chassis - Part 37.step
    [Main chassis - Part 37.step]
2026-06-13 Rename 3D MODELS/Suspension/Main chassis - Part 37.step to 3D MODELS/Main chassis - Part 37.step
    [Main chassis - Part 37.step]
2026-06-13 Create MCQUEEEN - ALL compnents.csv
    [MCQUEEEN - ALL compnents.csv]
2026-06-20 Update MCQUEEEN - ALL compnents.csv
    [MCQUEEEN - ALL compnents.csv]
2026-06-20 3D models
    [FULL ASSEMBLY (DO NOT PRINT).step, Main chassis - Part 1 (1).step, Main chassis - Part 1 (2).step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]
2026-06-21 Update Chassis for magnet incorporation
    [Main chassis - Part 51.step, Main chassis - Part 52.step, Main chassis - Part 53.step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]
